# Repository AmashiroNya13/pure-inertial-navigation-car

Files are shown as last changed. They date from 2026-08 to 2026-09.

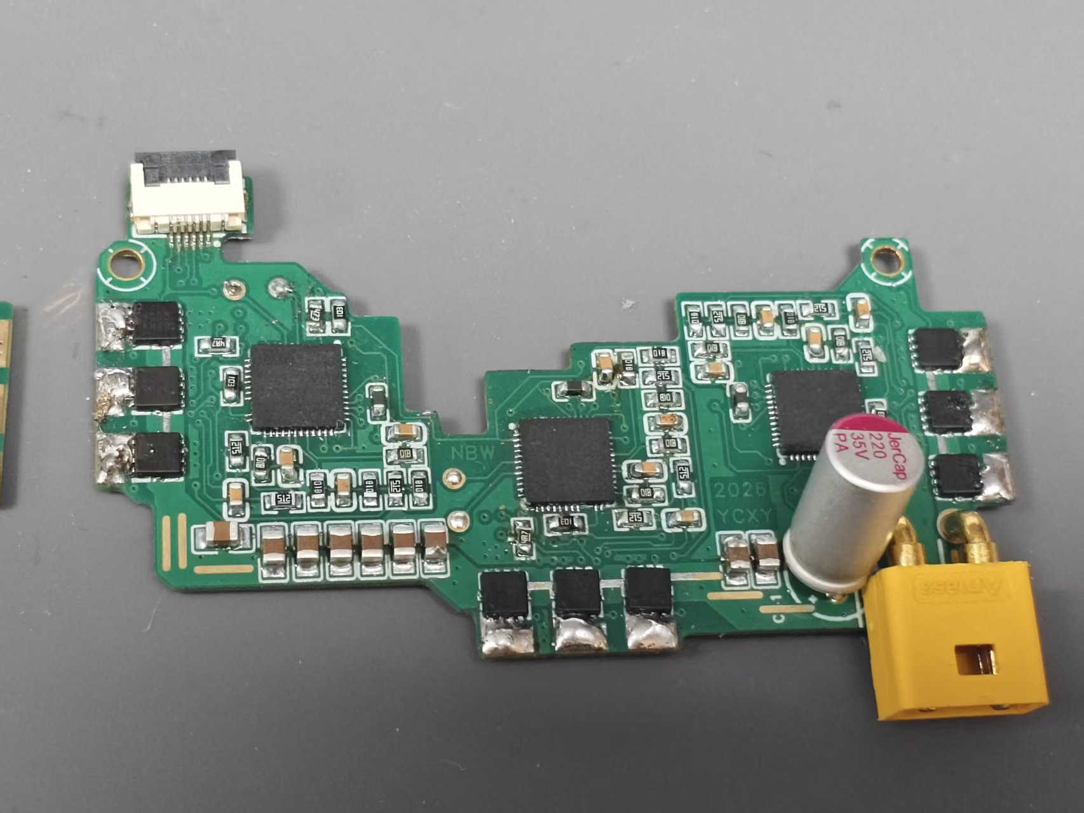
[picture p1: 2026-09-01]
images/4c2e1453128bda9ba8b21bae105e2d56.jpg

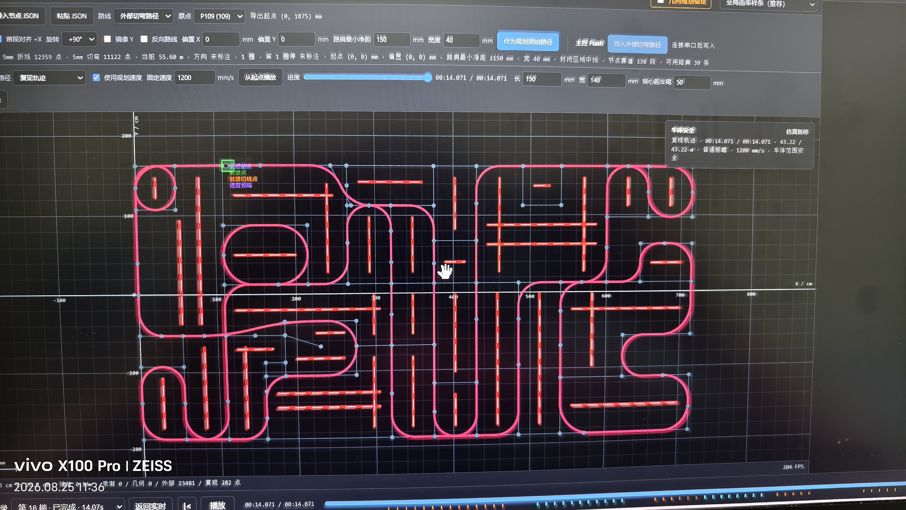
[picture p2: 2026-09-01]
images/IMG_20260825_113613.jpg

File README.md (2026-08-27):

# 21届纯惯导车开源项目

本仓库整理了纯惯导小车的控制软件、上位机工具、硬件资料和机械资料。项目用于路径采集、节点地图规划、路径上传、纯惯导复现与数据可视化。

> 安全提示：本项目涉及高速电机、无刷电调、负压和移动平台。首次使用必须架空车辆，使用保守的速度与加速度参数，并确认急停可用。

> **重要文档**：
> - [纯惯导软件设计说明](docs/INERTIAL_NAVIGATION_SOFTWARE.md)：IMU、编码器、双自由度角度环、速度前馈、路径与修正思路。
> - [纯惯导机械设计说明](docs/INERTIAL_NAVIGATION_MECHANICAL.md)：电机、负压、结构、减振、底盘和装配经验。
> - [纯惯导硬件设计说明](docs/INERTIAL_NAVIGATION_HARDWARE.md)：电调、双 IMU、屏蔽、编码器连接和后续硬件方向。
> - [机械采购与加工清单（Excel）](docs/MECHANICAL_PROCUREMENT_LIST.xlsx)：采购链接、CNC/3D 打印需求、在售核验与下单规格。

## 目录

```text
.
├── software/
│   ├── firmware/
│   │   ├── main-controller/ # TC2xx 主控：惯导、路径、速度和姿态控制
│   │   ├── drive-esc-ai8051u/   # 行进电机 AI8051U 电调
│   │   └── suction-esc-ai8051u/ # 负压电机 AI8051U 电调
│   └── tools/
│       ├── PathCapture/     # 串口上位机、路径上传与复现数据可视化
│       └── path-tools/      # 节点坐标规划器、路径日志查看器
├── hardware/
│   ├── schematics/        # 主控原理图
│   └── README.md          # PCB、BOM 与接线资料的发布约定
├── mechanical/            # CAD、装配图与机械 BOM
├── docs/                  # 使用、接口与调参说明
└── archive/               # 本地导入归档，不应推送到公开仓库
```

## 快速开始

### PathCapture 上位机

需要 Python 3.8 或更高版本。Windows 下双击：

```text
software/tools/PathCapture/launch.bat
```

首次启动会创建本地 `venv` 并安装依赖，浏览器随后打开 `http://localhost:5000`。更多使用方法见 [software/tools/PathCapture/README.md](software/tools/PathCapture/README.md)。

### 节点坐标规划器

直接使用浏览器打开：

```text
software/tools/path-tools/tools/node_coordinate_viewer.html
```

它可导入节点坐标、手动连接路线、做切弯与速度规划，并导出供 PathCapture 使用的 JSON。

## 发布前待补资料

- 在 `hardware/` 放入原理图、PCB、BOM、供电与接线说明。
- 在 `mechanical/` 放入 CAD 源文件、导出 PDF、装配说明和紧固件清单。
- 填写实车参数与安全范围，尤其是轮距、轮周长、减速比、PWM 上限和负压配置。

## 授权状态

当前尚未指定仓库整体许可证。公开前请逐项核对芯片 SDK、IDE 模板、逐飞库及其他第三方内容的原始许可证与再分发条件，再为你拥有版权的内容添加 `LICENSE`。

已识别到的第三方组件和发布边界见 [docs/THIRD_PARTY_NOTICES.md](docs/THIRD_PARTY_NOTICES.md)。

## 致谢与上游

主控工程的早期基础参考了 [XCELINE / MotorCycle](https://gitee.com/xceline566/motorcycle) 的第二十一届智能车单车定向开源项目。感谢 XCELINE 公开基础工程与文档。

本仓库不是该项目的官方分支：路径复现、车辆控制、速度与姿态策略、串口协议、路径工具及上位机均已进行了大量改动和扩展。上游来源、版本与许可证边界见 [docs/UPSTREAM.md](docs/UPSTREAM.md)。

`archive/` 存放本次整理前的原始导入压缩包，仅供本地追溯，已由 `.gitignore` 排除。

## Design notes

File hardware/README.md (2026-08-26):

# 硬件资料

`schematics/` 当前包含主控原理图 PDF。请在此目录继续放入与公开版本一致的：

- 原理图 PDF 与源文件
- PCB 生产文件和版本号
- BOM 与可替换料说明
- 接线图、供电范围、接口定义
- 传感器、电机、电调和负压模块的型号与安装方向

建议将每个 PCB 版本的生产文件、BOM、装配图放在同名版本子目录中。不要提交包含账户、订单、收货信息或厂商私有工程数据的文件。

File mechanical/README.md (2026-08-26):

# 机械资料

请在此目录放入与公开版本一致的：

- CAD 源文件与通用交换格式（STEP/DXF/PDF）
- 整车装配图
- 零件清单与紧固件规格
- 关键尺寸、材料、加工和安装注意事项

建议在每次改版时在文件名或附带的变更记录中标明版本。

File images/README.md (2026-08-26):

# 文档图片

本目录用于 README、使用说明和发布页中的展示图片，不存放原理图、PCB 生产文件或 CAD 源文件。

建议按以下名称放置图片：

| 文件名 | 内容 |
| --- | --- |
| `vehicle-overview.jpg` | 完整车辆正面或俯视图 |
| `vehicle-undercarriage.jpg` | 底盘、轮组与负压结构 |
| `electronics-overview.jpg` | 主控、行进电调、负压电调与接线概览 |
| `pathcapture-overview.png` | PathCapture 上位机界面 |
| `node-planner-overview.png` | 节点路径规划器界面 |
| `track-run.jpg` | 赛道运行或路径复现画面 |

图片应避免展示个人信息、串口号、账号、订单或无关的电脑桌面内容。优先使用清晰的 PNG/JPEG，并保持单张图片在合理体积内。

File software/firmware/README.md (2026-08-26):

# 固件工程

## 子项目

| 目录 | 目标 | 工具链 |
| --- | --- | --- |
| `main-controller/` | 车辆主控、惯导路径、速度与姿态控制、串口协议 | Infineon AURIX Development Studio + TASKING |
| `drive-esc-ai8051u/` | 行进电机的 AI8051U 无刷电调 | Keil C251 |
| `suction-esc-ai8051u/` | 负压电机的 AI8051U 无刷电调 | Keil C251 |

三个固件工程需要分别编译、烧录。两块 AI8051U 板不能混刷：行进电调接收主控的行进 PWM，负压电调只驱动负压电机。每次烧录前都应核对目标板、接线、电源与对应目录。

## 第三方代码

`main-controller/Libraries/`、两套电调的逐飞组件、芯片头文件、SDK 及 IDE 工程模板可能带有独立许可证。公开发布前必须保留各文件原有版权声明，并按原许可证确认是否允许再分发和商用。

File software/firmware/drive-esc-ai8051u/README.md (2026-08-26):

# 行进电机 AI8051U 无刷电调固件

这是行进电机使用的 AI8051U 无感六步换相电调工程，使用 Keil C251 构建。它与同级 `../suction-esc-ai8051u/` 的负压电调是两套独立固件，不能混刷。

## 构建

1. 安装 Keil C251 与工程依赖的逐飞库。
2. 打开 `project/` 下的 `.uvproj` 工程文件。
3. 确认目标是行进电调板，并在不接动力电机或使用受限电源的条件下完成首次烧录与验证。

## 关键配置

主要控制参数在 `bldc/bldc_config.h`，包括 PWM 范围、最小/最大占空比、开环换相次数、闭环等待次数、速度增量限制和电机进角。

电调输入与主控 PWM 的协议、频率和量程必须一致。修改前先记录原始值；任何更改都应在架空状态验证低油门启动、停转、欠压保护和失控保护。

## 第三方声明

本目录含逐飞库与模板代码。必须保留原始文件头和版权信息，并在公开发布前确认原始许可证是否允许再分发。

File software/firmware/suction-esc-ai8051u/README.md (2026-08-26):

# 负压电机 AI8051U 无刷电调固件

这是负压电机使用的 AI8051U 无感六步换相电调工程，使用 Keil C251 构建。它与同级 `../drive-esc-ai8051u/` 的行进电调是两套独立固件，不能混刷。

## 构建

1. 安装 Keil C251 与工程依赖的逐飞库。
2. 打开 `project/` 下的 `.uvproj` 工程文件。
3. 确认目标是负压电调板，在不接负压电机或使用受限电源的条件下完成首次烧录与验证。

## 关键配置

主要控制参数在 `bldc/bldc_config.h`。负压电机的 PWM 量程、最大占空比、保护阈值与响应限制应按负压系统单独设置，不能复制行进电机参数。

## 第三方声明

本目录含逐飞库与模板代码。必须保留原始文件头和版权信息，并在公开发布前确认原始许可证是否允许再分发。

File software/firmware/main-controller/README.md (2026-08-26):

# 主控固件

这是基于 Infineon AURIX TC2xx 的 ADS/TASKING 工程，包含纯惯导路径记录与复现、速度环、航向控制、路径上传、光电与滑移观测相关模块。

## 打开与构建

1. 安装与工程匹配的 AURIX Development Studio、TASKING TriCore 工具链和芯片 SDK。
2. 在 ADS 中导入本目录为现有 Eclipse 工程。
3. 选择 `Mad_Circuits TriCore Debug (TASKING)` 构建配置。
4. 在未接电机的条件下先检查引脚、时钟、PWM、编码器、IMU 和串口配置。

工程链接脚本为 `Lcf_Tasking_Tricore_Tc.lsl`。构建产物应生成在本机目录，已由仓库根目录 `.gitignore` 排除。

主控原理图位于仓库根目录的 `hardware/schematics/`，不再混放在固件目录。

## 主要模块

| 路径 | 职责 |
| --- | --- |
| `src/app/module/module_vehicle_control/` | 速度、姿态、起步状态机与 PWM 输出 |
| `src/app/module/module_vehicle_path/` | 路径记录、规划、上传、复现与位置估计 |
| `src/app/module/module_vehicle_encoder/` | 轮速和编码器观测 |
| `src/app/module/module_vehicle_gyro/` | IMU 与姿态观测 |

## 参数与安全

实车参数和 PID 不应直接照搬。首次移植应从低速、低加速度、架空测试开始，逐项校验轮周长、轮距、减速比、编码器方向、电机方向、IMU 轴向和急停逻辑。

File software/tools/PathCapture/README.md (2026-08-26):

# PathCapture — High-Performance Real-Time Path Display

A high-performance, real-time 2D path visualization tool for robotics and embedded systems. Receives coordinate data via serial port and renders it on a Canvas-based web interface with smooth zooming, panning, and 20k+ point support.

## Features

- **Real-time rendering** — Canvas2D with `requestAnimationFrame` loop; handles 20,000+ points at 60 FPS
- **Serial data ingestion** — Reads `R(car_x,car_y),(lookahead_x,lookahead_y)` and `P(x,y)` messages via serial port
- **Three data layers** with independent visibility toggles and distinct colors:
  - 🟦 **Predefined Path** (persistent, blue)
  - 🟥 **Real-Time Track** (appends on arrival, red, with direction arrow)
  - 🟩 **Lookahead Point** (latest shown by default, toggleable history, green)
- **Zoom & Pan** — Mouse wheel zoom (centered on cursor), click-drag pan, pinch-to-zoom on touch devices
- **Auto-Fit** — Animated fit of visible data to the viewport
- **Light/Dark theme** — Default light theme with dark mode toggle; persists across sessions
- **Serial port picker** — Direct dropdown (no submenus); auto-refresh; baud rates up to 2,000,000
- **Replay sessions** — Each confirmed replay is stored as an independent run with a shared elapsed-time axis
- **Serial command console** — Send commands and inspect filtered RX/TX replies in the same window
- **Data persistence** — Save the baseline path and all replay runs as a version 3 JSON file
- **Status bar** — Live mouse world coordinates, zoom level, point counts, FPS
- **Keyboard shortcuts** — Arrow keys pan, `+`/`-` zoom, `F` or `0` auto-fit
- **Responsive** — Works on desktops and tablets; touch-friendly

## Quick Start

### Prerequisites

- Python 3.8 or later
- pip (Python package manager)

### Launch

**Linux / macOS:**

```bash
chmod +x launch.sh
./launch.sh
```

**Windows:**

```cmd
launch.bat
```

The script will:
1. Check for Python
2. Install dependencies (`flask`, `flask-socketio`, `pyserial`)
3. Start the web server on `http://localhost:5000`
4. Open your default browser automatically

### Manual Setup

```bash
cd PathCapture
pip install -r requirements.txt
python app.py
```

Then open **http://localhost:5000** in your browser.

## Usage

### Workspaces

The top segmented control separates tasks that use the same map:

- **实时监控** keeps serial recording, replay, emergency stop and run playback together.
- **规划验证** compares the untouched path, browser geometry result and firmware-equivalent speed plan. The path cursor shows the nearest/base point, steering lookahead, tangent sample and independent speed-preview point. A lateral-offset input makes cross-track behavior visible without altering the stored path.
- **外部路径** imports node-map JSON, previews the node polyline and exported cut-corner samples independently, then optionally promotes the selected route to the planning workspace.

The curvature and speed charts are linked by path distance. The speed chart exposes curvature, wheel-speed, forward-acceleration, backward-braking and final constraints instead of presenting only the final planned speed.

### Connecting to a Device

1. Connect your embedded device via USB serial
2. Select the **serial port** from the dropdown (click 🔄 to refresh)
3. Choose the **baud rate** (default: 115200; supports up to 2,000,000)
4. Click **Connect**

### Vehicle workflow

The mode badge follows vehicle replies; clicking a button does not change the mode optimistically.

| Action | Serial command | PathCapture behavior |
|---|---|---|
| Start recording | `vpath record` | Wait for `{pathinfo}record_start`, then clear the old blue baseline and display incoming path points |
| Stop and save recording | `vpath record stop` | Keep the completed blue path as the baseline |
| Start replay | `vpath replay` | Start a new replay run after the vehicle confirms replay start |
| Emergency stop | `vstop` | Send immediately; the current replay run is closed when stop/safety feedback arrives |

After replay finishes or stops, select a run at the bottom and use the time slider, play/pause button and speed selector. Imported files keep their recorded path as the blue baseline until the vehicle confirms a new recording.

### Geometry validation

Enter **规划验证** to configure browser-only geometry and speed planning:

- Blue points are the untouched recorded path.
- Orange points are the reconstructed geometric path.
- Every coordinate layer has an independent visibility switch. Recorded, geometry, firmware, external, replay and lookahead points can be compared and inspected in any workspace.
- **全局曲率样条（推荐）** fits one cubic parametric spline across the complete path. Detected straight sections receive strong TLS line constraints, while second- and third-control-difference penalties suppress curvature and curvature-rate discontinuities through compound and S bends.
- **分段回旋圆弧（旧）** keeps the earlier independent `line -> clothoid -> arc -> clothoid -> line` corner reconstruction for comparison.
- The curvature chart plots signed curvature against path distance. Hover an orange point to inspect its geometry type, curvature and radius.
- Enable **限制最小半径** and enter a radius in millimeters to search progressively smoother global splines. A result is marked **已满足** only after every planned point passes `abs(kappa) <= 1 / radius` and the complete curve remains inside the 120 mm offset guard. Dashed red lines show the selected curvature bound.
- Enable **横向偏移优化（实验）** to add coarse lateral-offset control points along the global spline. The browser performs projected coordinate searches inside the 120 mm corridor, directly penalizing curvature-limit violations, excessive displacement and abrupt offset changes. This can move individual bends instead of only increasing one global smoothing factor.
- The experimental optimizer is browser-only and intentionally disabled by default. It preserves path order but does not yet model measured left/right track boundaries, vehicle footprint or prove that the optimized path is globally optimal.
- **未满足** means the current search family did not find a valid curve inside the offset guard; it is not a mathematical proof that no possible path exists.
- A planned curve that still exceeds the 120 mm source-path offset guard after relaxation is rejected and displayed as the resampled source path.

The validator never overwrites the recorded path, sends planned points to the vehicle or changes replay control. The recommended method is a constrained parametric spline with curvature-related regularization; it is not yet a nonlinear direct optimization of `kappa(s)`.

### External node maps

Node-map JSON exported by `tools/node_coordinate_viewer.html` is accepted directly. Supported fields include `nodes[]`, `start_node_id`, `computed_shortest_route.full_path_node_ids` and `computed_shortest_route.speed_segments[].points_mm`.

The node viewer provides **下载 JSON** for a normal file workflow. Its **复制导出文本** output can also be pasted directly through PathCapture's **粘贴 JSON** dialog.

- The exported `start_node_id` is selected by default and remains at its exported `(x_mm, y_mm)` position.
- Editable start X/Y fields default to the exported start coordinates and translate the complete route to that absolute position.
- Selecting another origin restarts a closed route at that node and resets start X/Y to that node's exported coordinates.
- A shoulder layer is enabled by default on both sides of the selected external route. Its inner edge is 150 mm from the path and its width is 40 mm; both values remain editable.
- **首段对齐 +X** rotates the first route segment onto the inertial positive X axis.
- Additional `0°`, `+90°`, `-90°`, `180°`, Y mirroring and route reversal controls are applied around that origin.
- **节点折线路径** is the recommended raw input for browser geometry planning.
- **外部切弯路径** is a comparison layer by default, avoiding accidental double optimization.
- Exported coordinates do not carry the source tool's display-only `Y 向下` setting, so orientation is always explicit in the import controls.
- Imported X/Y controls are relative offsets and therefore start at `0, 0`; the exported origin coordinates remain the transform base. Shoulders are generated only from external node-track links, never from cut-corner samples. Each bounded region receives one thick line along its longer axis. The line starts from average Y or X, then follows the local maximum-clearance center as nearby node-road segments move inward. Every interpolated centerline section must retain the configured clearance plus half the shoulder width; impossible sections are omitted instead of crossing the road.
- The vehicle collision switch wraps the replay arrow with the configured body footprint. The replay coordinate and `theta_deg` define the motion-center pose; with the default 150 mm length and 50 mm rear-to-center mounting distance, the body extends 100 mm forward and 50 mm rearward from that point. Each safe-to-collision transition records replay time, traveled distance and coordinates.

The firmware speed planner uses the current defaults: 400-3200 mm/s, 25,000 mm/s² lateral and longitudinal limits, a 120 mm wheelbase, 200 mm at 500 mm/s after launch, and 300 mm terminal deceleration. These values can be adjusted in the planning workspace for comparison; browser planning does not write Flash or send commands to the vehicle.

### Data Format

The tool is adapted for the current Mad_Circuits serial replies. Each message must end with `\n` or `\r\n`.

| Format | Description | Layer |
|---|---|---|
| `{pathdump}index,x_mm,y_mm,theta_rad,speed_mm_s` | Dumped recorded/planned path point | Blue path |
| `{path}x_mm,y_mm,theta_deg,index,record_dist_mm,...` | Path point printed while recording | Blue path |
| `{vrpl1}pose_x_mm,pose_y_mm,pose_theta_deg,base_x_mm,base_y_mm,base_theta_deg,cte_mm,along_mm,target_x_mm,target_y_mm` | Replay pose + current tracking target | Red track + green target |
| `{vrpl2}...` | Target/actual wheel speed and compact angle diagnostics | Point details |
| `{vrpl3}...` | Target/final wheel PWM and ESC fault state | Point details |
| `{vrpl0}...`, `{vrpl4}...`, `{vrplg}...` | Point index, lookahead and replay startup phase | Point details |
| Binary replay frame `A5 5A` | Default compact equivalent of `{vrpl0}` through `{vrpl3}`; decoded by the backend | Red track + point details |
| `{vmark}add,kind,index,x_mm,y_mm,theta_deg` | Manual turn-in/turn-out marker | Green target layer |

Legacy `P(x,y)` and `R(car_x,car_y),(lookahead_x,lookahead_y)` lines are still accepted for compatibility.

Replay telemetry defaults to the compact binary frame. Use `vtelemetry text` for legacy text diagnostics,
`vtelemetry binary` to restore the compact mode, and `vtelemetry status` to query the current mode.
Speed-loop ground tests keep the original `{vspd}` text packet unchanged.

**Examples:**

```
{pathdump}0,100.000,200.000,1.570796,500.000
{path}110.000,210.000,90.000,1,12.000,0,0,0,0,0,0,0,0,0,0
{vrpl1}120.0,220.0,91.00,111.0,211.0,90.0,9.0,10.0,150.0,250.0
{vmark}add,in,3,130.000,230.000,92.000
```

- `{pathdump}begin,...` clears the blue path before a new dump, preventing repeated dumps from stacking.
- Firmware coordinates are millimeters; map axes and mouse coordinates are labeled in centimeters.
- Hover a point to inspect position, tracking target, cross-track error, planned/actual speed, wheel speed and PWM.
- Enable **Diagnostics** only when tuning the controller. It adds angle/yaw, tangent, base-point and ESC details.
- Deep diagnostics (`vrpl5/6/7`), IMU raw data, phototube data, Flash logs, startup messages, malformed lines and unknown prefixes are intentionally filtered out.
- Saved files contain structured visualization data only. Raw serial lines are no longer duplicated into the JSON file; version 1 files remain loadable.

### View Controls

| Action | Control |
|---|---|
| Zoom | Mouse wheel / `+` `-` keys / toolbar buttons |
| Pan | Click & drag / Arrow keys |
| Auto-fit | **Auto Fit** button / `F` key |
| Pinch-zoom | Two-finger gesture (touch devices) |

### Visibility Toggles

Use the checkboxes in the toolbar to show/hide:

- **Path** — Predefined trajectory points (blue)
- **Real-time** — Live car track (red)
- **Lookahead** — Preview point (green)
- **History** — When checked, all past lookahead points are displayed instead of only the latest

### Saving & Loading Data

- **Save** — Downloads a version 3 JSON file containing the baseline and every replay run
- **Load** — Click **Load**, select a `.json` file (previously saved or server-generated)

The JSON format:

```json
{
  "version": "3.0",
  "saved_at": "2026-07-14T14:00:00",
  "predefined": [{"x": 1.5, "y": -2.3, "t": 0.001}, ...],
  "realtime":  [{"x": 0.0, "y": 0.0, "t": 0.002}, ...],
  "lookahead": [{"x": 1.5, "y": -2.3, "t": 0.002}, ...],
  "replay_runs": [{
    "id": 1,
    "status": "completed",
    "points": [{"x": 0.0, "y": 0.0, "elapsed_s": 0.0}, ...],
    "lookahead": [{"x": 1.5, "y": -2.3, "elapsed_s": 0.0}, ...]
  }]
}
```

Version 2 flat files are accepted and are converted to one imported replay run in memory.

## Architecture

```
PathCapture/
├── app.py                  # Flask + Socket.IO backend; serial reader thread
├── static/
│   ├── index.html          # Single-page application shell
│   ├── style.css           # Light/dark theme, responsive layout
│   ├── app.js              # Canvas2D renderer, socket.io client, interaction
│   ├── geometry-planner.js # Browser geometry algorithms
│   ├── firmware-speed-planner.js # Firmware-equivalent speed constraints
│   └── external-path.js    # Node-map parsing and coordinate transforms
├── launch.sh               # Linux/macOS launcher
├── launch.bat              # Windows launcher
├── requirements.txt        # Python dependencies
└── README.md               # This file
```

### Data Flow

```
Embedded Device ──(serial)──> Serial Reader Thread ──> process_line()
                                    │
                              socketio.emit('serial_data')
                                    │
                              WebSocket ──> Browser ──> Canvas2D Renderer
```

## Performance Notes

- Uses **Canvas2D** with view-transform rendering — point coordinates never change, only the transform matrix
- Grid lines are clipped to prevent excessive draw calls at extreme zoom levels
- Dirty-flag optimization avoids re-rendering when nothing changes
- Device pixel ratio clamped to 2x for sharp rendering without excessive GPU load
- Tested rendering 20,000+ polyline points at 60 FPS on modern hardware

## Troubleshooting

| Issue | Solution |
|---|---|
| "No ports found" | Ensure device is connected and drivers are installed; click 🔄 to refresh |
| "Access denied" (Linux) | Add user to `dialout` group: `sudo usermod -a -G dialout $USER` (log out/in after) |
| Port in use | Close other terminal/serial monitor programs (Arduino IDE, PuTTY, screen, etc.) |
| Page shows "Unable to connect" | Ensure `python app.py` is running; check port 5000 isn't in use |

## License

MIT

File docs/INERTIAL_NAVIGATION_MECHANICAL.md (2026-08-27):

# 纯惯导机械

> 本文记录本车的机械设计思路、实际选型与后续设想。性能数据来自作者当时的实车记录，受轮胎、负压、赛道、电池和装配状态影响很大，不应直接作为复现或安全边界；首次调试请从保守速度和加速度开始。

## 设计目标

机械设计的目标是在保持低重量和高性能的同时，保留可拆装、可调整的结构，并尽量控制成本。装配复杂度可以接受，但必须换来可靠的车载平台和明确的维护空间。

## 行进与负压

- **行进电机**：T-Motor 1404、3800 KV 外转子无刷电机。作者记录的 3S 工况下持续转速约为 32000 RPM、电流约为 10 A；选择重点是尺寸不遮挡轮毂安装、转速合适、扭矩和电压匹配，以及可实现的减速比。
- **负压电机**：致盈动力 1202.5、6000 KV 无刷电机，配合龙邱方案扇叶。作者曾记录到约 1600 g 负压，实际可用上限仍需实测确认。
- **车辆记录**：原车采用六步换向驱动，纯惯导版本重量约 99 g；作者曾观察到约 1000 g 负压、约 9 A 电流的工况。轮胎摩擦系数和负压效率是性能上限的主要约束，不能仅由电机转速推断过弯能力。

## 结构与材料

- 主结构使用碳纤维底板和加强筋，配合 TA2 钛合金螺丝、超小碳钢螺丝、铝柱。
- 带齿轮的一体化轮毂采用嘉立创 3D 打印 PA12S。
- 轮轴使用两颗 PEEK 轴承、垫片、PEEK 螺丝和铝柱。四个车轮共八颗轴承，载荷有较大余量；相对于碳钢轴承，该方案有利于减重。
- 编码器固定采用 PEEK 螺丝、带螺纹铝边板和铝柱组成的刚性平台。磁铁间距约 1 mm，通过 FPC 连接主板，作者实测数据稳定。

## 减振与 IMU 安装

主 PCB 与 IMU 小板分离安装。TC264 主板上放置聚氨酯海绵，IMU 小板上的洋白铜屏蔽罩通过 FPC 与主板传递数据。作者实测，该方案可隔绝大部分 6000 KV 无刷电机在约 83% 油门以内的振动。

减振件必须在载荷下产生弹性形变，才能通过能量耗散发挥作用。后续可把主板从加强筋结构中独立出来，改用飞控常见的球形减振柱；是否更优仍应以 IMU 数据验证。

## 光电管与底盘

光电管需要相对平稳的检测面。由于前置结构可能使悬空底板振动，车头采用较轻的铝合金盘头螺丝作为滑动支撑，略高于底盘，以获得少量负压并改善数据清晰度。

底盘并非越低越好：负压会向下压车，而此类车辆轮距较大，底盘触地会使负压失效。底盘离地高度应结合负压膜投影面积、赛道平整度和触地风险一起设计。当前车辆重心整体均衡、略偏后，离地高度在约 1 cm 以内。

## 装配与可调性

- **CNC 加工要求**：所有需要螺丝固定的 CNC 件，下单时必须按图增加并加工 **M2 螺纹孔**；不得只保留普通定位孔或光孔。加工完成后应使用 M2 螺丝逐孔试装，确认螺纹完整、孔位与装配体一致。
- 铝柱相对于常见尼龙柱可把外径压缩到约 3.5 mm，有利于 PCB 开孔、留白和螺丝固定；缩小体积后重量也接近或优于尼龙柱。
- PEEK 螺丝比尼龙螺丝刚度高，适合需要可靠夹紧的小型结构，同时保持轻量。
- 电池接口可在比赛常用的 300 mAh 与 180 mAh 小电池之间转换。为便于安全插拔，建议使用独立转接线。
- 加强筋上的两道槽用于扎带限位电池的左右及部分上下运动；需要更强限位时，可在电调上方增加 3M 胶辅助固定。
- 边板的椭圆槽用于调整轮毂齿轮啮合松紧，并为更换减速比保留位置。

## 后续方向

若负压、轮胎和结构进一步优化，车辆上限仍有提升空间。作者曾设想更高负压、更小减速比、4600 KV 电机或 4S 电池等方案；这些改动会显著提高机械、电调、热管理和安全要求，必须重新完成静态、架空和低速实车验证。

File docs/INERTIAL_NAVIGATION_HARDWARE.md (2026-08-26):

# 纯惯导硬件

> 本文记录本车硬件架构的设计经验。它不是可直接照抄的原理图或 BOM；供电、接地、烧录、散热和保护设计应以仓库当前硬件资料及实物验证为准。

## 电调架构

行进端采用逐飞 AI8051 电调方案，并改为一拖三结构；软件侧已做针对本车的调整。电调使用与构建说明见仓库中独立发布的行进与负压电调工程。

AI8051 的烧录接口必须预留。三块 8051 的反复烧录会直接影响维护效率；主控烧录口的串口可复用为高速无线串口，但使用前需确认电平、供电和串口复用状态。

## 双 IMU、减振与屏蔽

车辆采用双 IMU，通过洋白铜多点接地屏蔽电磁干扰，并帮助均匀分摊热量。

双 IMU 的价值主要在振动和零漂工况：当减振结构已能抑制主要振动时，两颗 IMU 的角度误差有机会呈相反趋势，平均后可让主体角度变化更缓慢。它不是无条件增益，必须以两路原始数据和融合结果验证。

洋白铜在本项目中承担多项作用：电磁屏蔽、散热均热、保护 IMU、粘接减振材料和增加适量配重。稳定的安装工况本身是惯导工程的重要部分。

## 编码器连接与磁屏蔽

编码器通过 FPC 连接到主板，体积小且实测数据稳定。项目曾设计 3D 打印屏蔽罩，但当前安装条件下未继续使用。

需要区分两类屏蔽：

- 良好接地的铝合金或铜对高频电磁场和电场屏蔽有帮助。
- 对强磁电机可能带来的低频磁场干扰，通常需要高磁导率材料，例如坡莫合金；普通接地铝或铜对此效果有限。

可行的机械方案是使用 3D 打印支架，使磁铁位于支架中，再将坡莫合金贴合在支架上形成磁屏蔽结构。是否需要实施应由编码器实际误码、角度稳定性和电机距离测试决定。

## 后续方向

后续硬件目标是继续提升供电、传感器和电调的稳定性，并评估 FOC 驱动方案。FOC 不只是替换算法，还涉及电流采样、PWM/ADC 同步、保护、位置反馈与整套驱动板设计，应作为独立硬件迭代完成验证。

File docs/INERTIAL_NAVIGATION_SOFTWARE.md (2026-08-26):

# 纯惯导软件

> 本文是本项目纯惯导软件的设计说明与工程经验记录。文中的频率、距离、阈值和参数用于说明当时的设计思路；实际默认值及可用范围应以当前源码和实车验证为准。

## 传感器

- **IMU**：负责航向偏移稳定。若航向歪斜，通常表现为路径整体旋转一个角度。
- **编码器**：负责横向误差锁定真实路径。若发生打滑，通常表现为平行路径但存在固定偏移。

偏移不止这两个因素，本文先聚焦于它们。

## 软件

### 1. IMU

IMU 获取角度通常有两种处理方式。

#### 1.1 角速度积分

主要由陀螺仪提供角速度，再根据某个时间戳完成积分。

1. **由主控提供时间戳**：会受到主控时间戳波动影响，而主控时间戳又受主控时序影响。因此应尽可能提高 IMU 数据处理优先级。这个思想同样适用于多数需要积分的场景，必须严肃考虑时序波动。
2. **由 IMU 提供时间戳**：理论上可能更准，但问题很多。最严重的是，这个时间戳并非 IMU 更新某条数据的时间戳，而是 IMU 自身当前时间戳，没有对数据点做标记；因此效果和主控时间戳相近，甚至可能更差。
3. **由 DMA 读取时获得时间戳**：这个时间戳较准确，实测可视为主控时间戳的上位推荐，能明显缓解时序不准问题，但实现仍有难度。

#### 1.2 IMU 自身四元数解算

由 IMU 自身完成独立四元数积分，输出 Game Rotation Vector 角，也就是向量角。该方式不必担心主控时序，也不会因 IMU 实时性要求侵蚀主控时序。

它仍有局限：难以进一步使用陷波等滤波算法，陀螺仪自身的静止修正算法精度有限，更新频率也较有限。滤波、静止修正和更新频率导致的问题在此不展开。

#### 1.3 本项目 IMU 与初始化现象

本项目使用 ST 的 LSM6 系列、带自解算四元数的版本。其自解算最高输出 480 Hz 角度数据，原始角速度和加速度最高输出 7000 Hz；此外还能读取温度、零偏修正数据和时间戳。

实测中，该 IMU 开启自解算 Game Rotation Vector 输出后的前 17 秒，数据会呈现“耐克状”弯钩，并可能形成永久性误差。因此上电后应禁止这 17 秒内的角度累计更新；期间并不要求车辆静止。

#### 1.4 零偏与外部干扰

IMU 数据通常包含零偏并会受到外部干扰。这里的外部干扰主要指负压振动和行进振动。

零偏通常由温漂、随机游走、电磁噪声和固定零偏构成：

- **温漂**可以通过恒温电路控制，但面对双 IMU、多 IMU、重量限制和布板限制，实现并不容易。一个思路是由主控通过 PWM 控制电阻的电流、电压以实现恒温；多 IMU 情况下 PWM 需求和复杂度都会增加。
- **随机游走**正负平均后通常不需要额外修正。
- **电磁噪声**个人观察中影响较大。这里主要隔离高频噪声，可使用马口铁、洋白铜、不锈钢，甚至铝合金进行多点接地隔离。项目中选择了约 0.15 mm 厚的洋白铜：不锈钢与马口铁款式较少，铝合金虽然更轻但难焊接、制作成本高，且担心焊接失败影响隔离效果。

固定零漂的处理思路是：关闭角度输出的自修正寄存器，把 IMU 静置在稳定桌面上，通过至少 409600 波特率的高速串口打印角度数据，确保环境没有异常振动，放置一整夜，再分析斜率以标定粗略零偏。

开机 17 秒后，使用加速度计、陀螺仪和编码器共同检测静止。静止时的加速度、角速度和编码器跳动数据可用于分析合理阈值。在连续共同静止的死区内，IMU 禁止角度更新，并在固定零偏粗略处理后做更细致的零偏处理。

为避免时间跨度过大导致修正不够实时，设计上每 5 秒解算并使用一次零偏。退出静止的阈值略小于进入阈值；采用计数退出机制，即运动状态 `+1`、非运动状态 `-0.5`。另外通过小数据窗口缓存，保证进入/退出判断过程中用于确认的帧也能按正确状态重新处理。目标是在上电 17 秒后，只要放下不动就进入静止状态，保持极低漂移并可实时修正；灵敏度达到点击鼠标或手放在桌上抖腿会被识别为运动，同时尽量避免误判。

外部干扰中，行进端因硅胶胎减振且相对稳定，影响可在一定程度上忽略。负压端固定在底板，高速旋转并与空气做功，抖动更大、频率更高、难抓取也难滤除。由于车况变化较大，基于模型的减振或陷波较难稳定标定，更适合从机械侧使用海绵减振、分板减振或减振柱等方案。

以上是作者对 IMU 软件的部分理解，请结合实际情况自行判断。

### 2. 编码器

本项目使用 SPI 通信的 14 位编码器，以 1920 Hz 通过 DMA 自主读取角度数据并计算差值，属于 M 法测速。相对 T 法，其高速性能更好；同时因时序准确，实际效果较好。

编码器算法本身没有特别复杂的计算。作者不建议为了抑制齿槽或齿轮效应带来的抖动而盲目增加低通滤波：这类抖动很难被有效滤除，低通滤波反而引入相位滞后。去掉不必要滤波后，响应可能更快、修正更及时、实际波动也可能更小。该结论应以具体硬件数据验证。

## 控制算法

电调侧采用六步换向和过零校正。主控侧输出 PWM，使用双串 PID：480 Hz 的双自由度角度环，连接 1920 Hz 的前馈速度环。

### 1. 双自由度角度环

惯导路径控制通过转向前瞻目标的 `x/y` 坐标与自身 `x/y` 坐标计算目标角度差，再送入角度环。角度环为作者实现的“双自由度 PD”：经典 PD 加微分先行 D，再用二自由度约束对两个 D 做加权调节。

设计来源于两种观察：

- 使用经典 PD 时，过弯通过率高，但摆动较大，路径不够准确。
- 使用微分先行 PD 时，贴路径效果很好，但偶发转弯突然失控，且失控位置可能高度一致。

二者融合后，在 PD 固定且不需要精确重新调参的情况下，可以主要调整自由度：自由度较低时，过弯成功率更高，但会带来更平滑、略超调且不再紧贴路径的感觉；自由度较高时，路径跟随更紧，但会降低过弯成功率。实测中较高自由度可达到较好的综合效果。角度环不建议额外使用前馈。

### 2. 速度环与前馈

角度环计算出的相反速度误差分别送到左右轮速度环。速度环由前馈加 PI 构成，速度目标值需经过加速度限制以限制速度阶跃斜率。这是速度规划的前置条件，可从源头降低打滑、起步翘头和停车翘尾风险。

加减速限制是最大限制。具体加减速能力应来自实车标定：在无角度环的闭环速度环直线测试中，于多个速度点测得稳定 PWM，形成前馈表；目标区间之间进行线性插值，即可得到相对准确的全速度段前馈。作者记录中，单 PI 响应约 40 ms、单前馈约 30 ms，二者结合可降至约 17 ms 或更低。最后通过 PWM tick 斜率控制输出左右轮 PWM，主控只需限制明显错误输出，电调侧保留更严格的限制。

### 3. 前瞻解耦

速度前瞻和角度前瞻分别影响基础目标速度和转向角度。因此，“角度环串速度环”在本项目架构中并非传统串级：传统串级中上一级输出全额管控下一级；这里角度环输出的是差速，速度环将差速叠加到基础目标速度形成最终目标速度。

将两类前瞻分开可解耦基础目标速度和角度控制。若解耦不到位，速度规划可能成为一厢情愿：作者曾在固定 3.5 m/s 与最高直道规划 3.5 m/s 的测试中发现，虽然后者会因摩擦力规划而在弯道降至约 2.5 m/s，直道仍可能比原本更快，而弯道反而无法通过。

后续将速度前瞻设为约 1 cm、转向前瞻约 21 cm 后，弯道通过率明显提高。速度前瞻调至 2 cm 时，在相同速度下出现约 5 cm 的严重横向打滑；调小后仍可能打滑但幅度较小。可见在较大加减速限制下，该阈值较严格。因此应优先确保速度与角度控制真正解耦，再讨论速度规划效果。

## 惯导路径与修正

### 1. 路径表示和导入

作者认为，仅计算和记录 `x/y` 坐标是较优的惯导路径表示；单纯曲率或路程记录缺少点间框架约束，难以纠正，只能反复复现。项目以约 5 mm 间隔记录一个 `x/y` 点到 Flash。

转向目标角由路径 `x/y` 坐标与实时自身位置计算，频率与转向环一致，为 480 Hz。高速时必须注意离散位置记录：转弯曲率变化应连续，否则会在某些帧引入运行毛刺和 `x/y` 错位。

因此路径使用 Web 工具导入并保存到 Flash，以便人为控制路径、平滑路径和降低曲率阶跃。若电调能接受更高的速度环频率，例如 2880 Hz，还可以固定基础速度并依据编码器单独改变路程，进一步提高操控能力；建议速度环频率选用基础频率的整数倍，优先为 2 的倍数。

### 2. IMU 与编码器交叉修正

惯导修正要求 IMU 和编码器分别维护一套角度。编码器角度依赖轮距计算，但实测中轮距随速度和转弯半径变化，难以细致标定，因此不建议过度追求单一精确轮距。

获得两套角度后，应持续比对最近窗口内的角度差变化。一旦评估差值过大，例如重合率低于约 84%，可把 IMU 角度视为编码器角度，并通过轮距反推编码器路程，以修正总里程。

Flash 读取必须使用缓冲区并进行无缝切换；否则不仅无法实时运行，也可能卡死并造成撞车风险。

### 3. 偏移来源与路径规划

惯导偏移可能来自：

1. 航向角漂移。
2. 坐标记录离散或遗漏。
3. 编码器打滑。
4. 路径本身的问题，即“以什么路径为复现基准”。

路径规划建议通过 Web 导入 5 mm 离散节点。该方法不仅支持提前切弯，也可以利用摩擦圆算法为每个点给出规划速度和切弯半径，对精准惯导控制有帮助；还可扩展禁修区等功能。

### 4. 当前前瞻设计与后续设想

作者记录的常态前瞻为：约 1 cm 速度前瞻、约 21 cm 转向前瞻，以及基于转向前瞻的约 3 cm 切线前瞻。车辆自身坐标超过上一个弯道的出弯点后会进入直线状态；此时前瞻直接盯住下一个弯道的入弯点，以获得更强的直道抗扰动效果。

后续可考虑为每个弯道建立标定：上位机将转弯处理为恒定转弯半径，摩擦圆算法得到相对稳定的弯道速度，每个导入点带规划速度。在恒定转弯半径、恒定过弯速度和恒定基础速度下跑一趟弯道，即可观察弯中横向偏差，并通过增减当前转向前瞻距离形成“速度-最佳前瞻距离”表。这样直道可按下一个弯道提前预瞄，弯道则按速度选择更合适的前瞻距离，使控制进一步精细化。

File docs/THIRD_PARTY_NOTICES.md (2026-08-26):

# 第三方组件与发布边界

本文件记录已识别的第三方内容。它不是许可证替代品；发布者须在推送公开远端前确认每个来源的具体再分发条件。

| 位置 | 来源/用途 | 当前处理 |
| --- | --- | --- |
| `software/firmware/main-controller/` 的早期工程基础 | [XCELINE / MotorCycle](https://gitee.com/xceline566/motorcycle)，GPL-3.0 | 本项目为大幅修改后的独立仓库，保留上游归因并遵守适用的 GPL-3.0 条款 |
| `software/firmware/main-controller/Libraries/` | Infineon AURIX TC26B iLLD、寄存器定义与平台组件 | 保留原始版权头；根据各文件原始许可证发布 |
| `software/firmware/main-controller/user/` 与工程模板 | Infineon/ADS 工程模板 | 保留原始版权头；不纳入未来自有代码许可证 |
| `software/firmware/drive-esc-ai8051u/` | 行进电机：逐飞科技 AI8051U 库与无刷电调工程 | 文件头说明含非商业限制，不能被仓库未来的 MIT/GPL 许可证覆盖 |
| `software/firmware/suction-esc-ai8051u/` | 负压电机：逐飞科技 AI8051U 库与无刷电调工程 | 文件头说明含非商业限制，不能被仓库未来的 MIT/GPL 许可证覆盖 |
| `software/tools/PathCapture/` | 本项目上位机与网页工具 | 作者需确认所有文件均为自有或兼容许可后再授权 |
| `software/tools/path-tools/` | 本项目节点规划与路径查看工具 | 作者需确认所有文件均为自有或兼容许可后再授权 |

## 发布建议

1. 自有代码与第三方目录分开授权，不要在根目录许可证中声称覆盖整个仓库。
2. 若逐飞代码没有明确的公开再分发授权，公开仓库应改为仅保留你的差异补丁、配置文件与获取说明。
3. 每次新增 SDK、算法库、字体、图片或数据文件时，都在本表补充来源和许可证。

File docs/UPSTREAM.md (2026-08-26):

# 上游来源

## MotorCycle

- 上游仓库：[XCELINE / MotorCycle](https://gitee.com/xceline566/motorcycle)
- 作者：XCELINE
- 本地核对的上游版本：`7d0cf85`
- 上游许可证：GNU GPL-3.0

本项目的 TC2xx 主控工程以该项目的早期工程结构和部分基础实现为起点，后续已对路径复现、车辆控制、速度和姿态策略、串口协议、路径工具与上位机进行了大量修改和扩展。

本仓库不是上游的官方 fork，也不应将后续新增内容归因给上游作者。与此同时，基于上游 GPL-3.0 代码的部分仍须遵守其适用的许可证义务；逐飞、Infineon 等其他第三方内容继续以各自原始许可证为准。

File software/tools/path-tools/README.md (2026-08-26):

# 路径规划工具

本目录提供无需构建的本地工具。

| 文件 | 用途 |
| --- | --- |
| `tools/node_coordinate_viewer.html` | 节点坐标导入、手动路线连接、切弯、速度规划与 JSON 导出 |
| `tools/amr_path_viewer.html` | 路径与惯导数据查看 |
| `tools/path_log_viewer.py` | 日志辅助查看工具 |

## 使用

直接用现代浏览器打开 `tools/node_coordinate_viewer.html`。规划完成后导出 JSON，再在 PathCapture 的“外部路径”页面导入。

## 测试

安装 Node.js 后，在本目录执行：

```powershell
node tools/test_node_coordinate_viewer.js
node tools/test_amr_path_viewer.js
node tools/test_node_radius_cdp.js
```

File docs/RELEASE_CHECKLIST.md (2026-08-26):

# 公开发布检查清单

- [ ] 删除或确认不包含本地绝对路径、串口号、个人信息和赛场数据。
- [ ] 不提交 `archive/`、`venv/`、缓存、日志、二进制和构建产物。
- [ ] 检查主控固件、电调、SDK 和逐飞代码的原始许可证与再分发条件。
- [ ] 确认硬件和机械文件的版本、单位、层叠和生产注意事项。
- [ ] 架空实车验证急停、最低速度、串口连接、路径上传与停止命令。
- [ ] 在一台未配置开发环境的电脑上按 README 从零启动 PathCapture。
- [ ] 选择仓库地址后初始化 Git，并在首次提交前执行 `git status --ignored`。

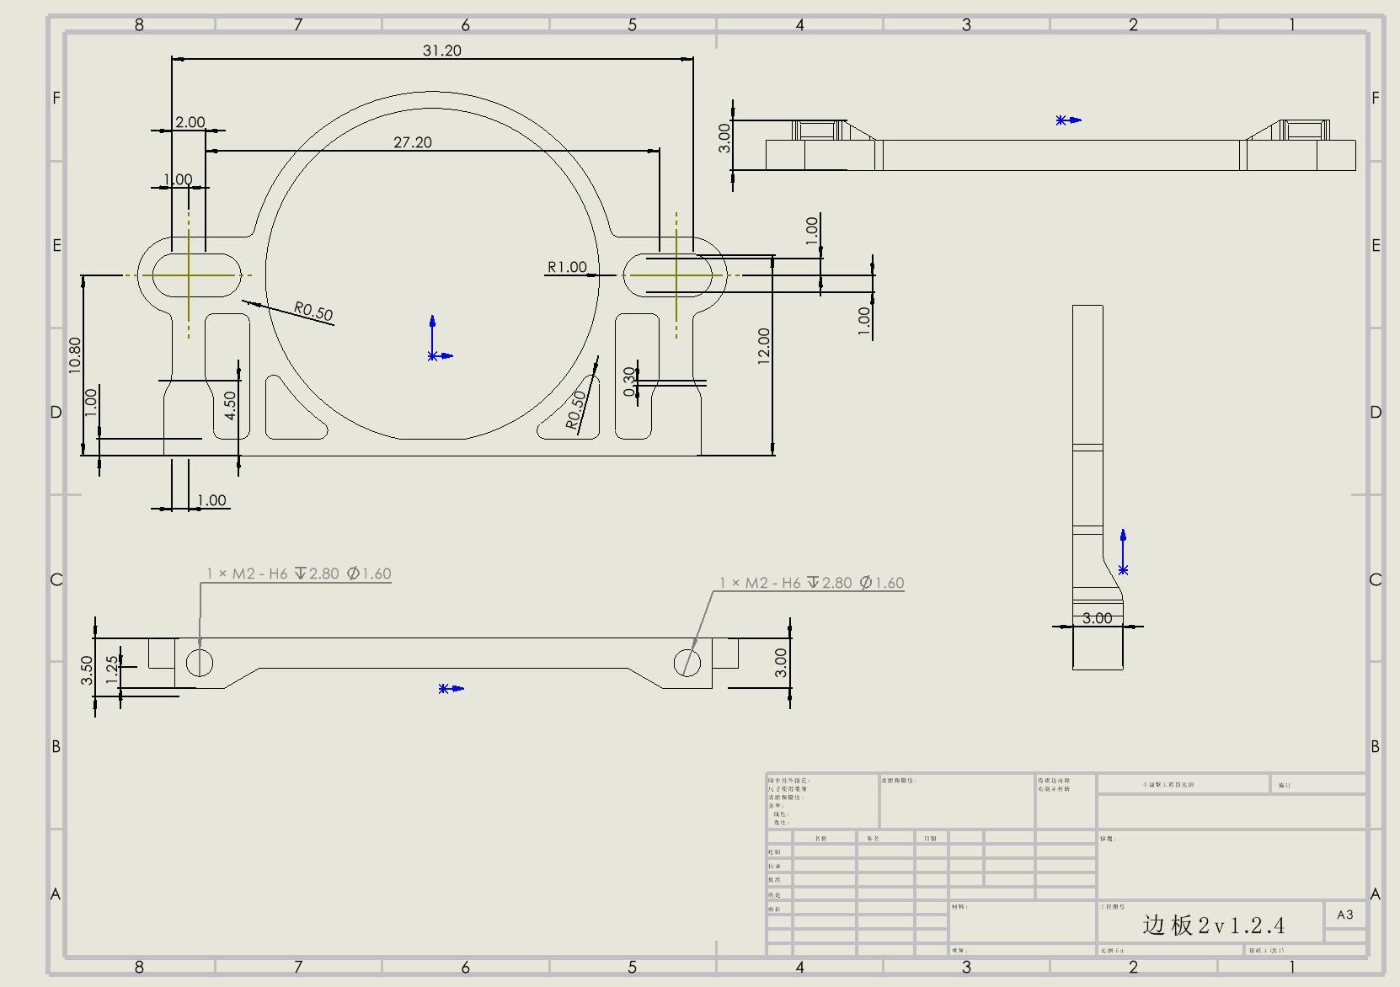
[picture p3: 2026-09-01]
mechanical/mechanical drawing/边板2v2.3.5.png

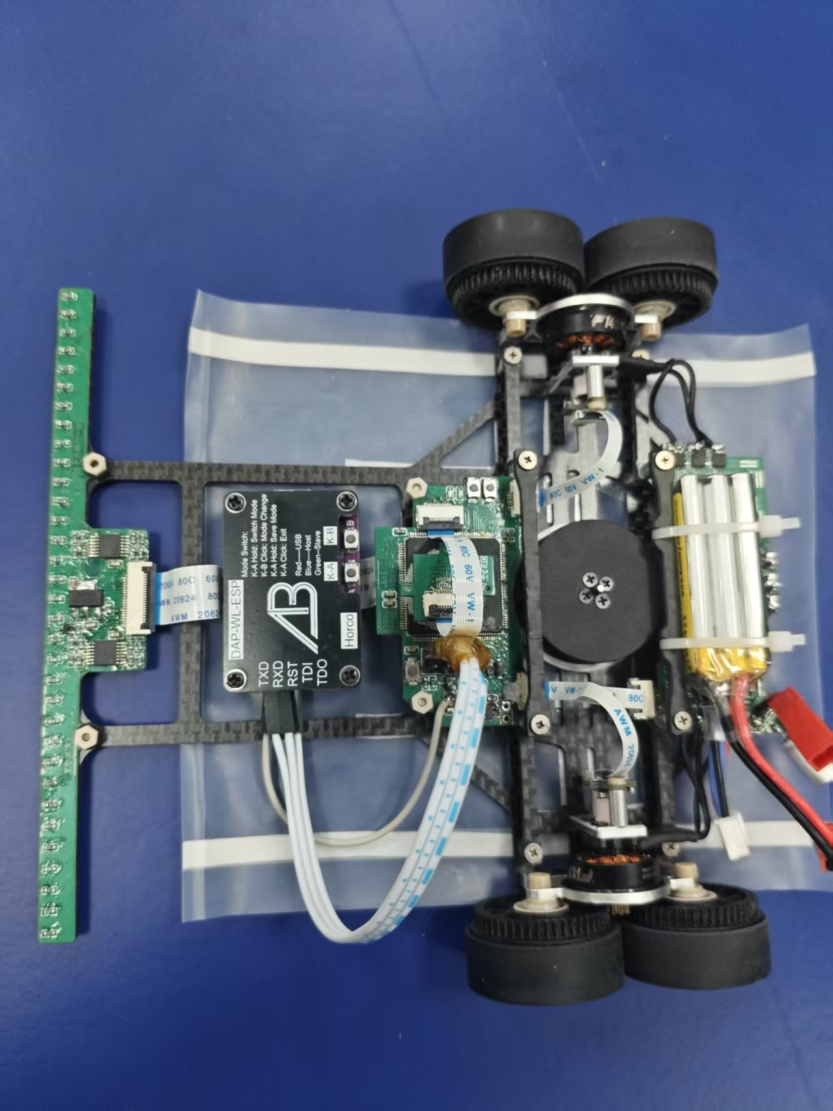
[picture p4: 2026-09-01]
images/f3f8274bfc2c42afd2de04dce35dd12d.jpg

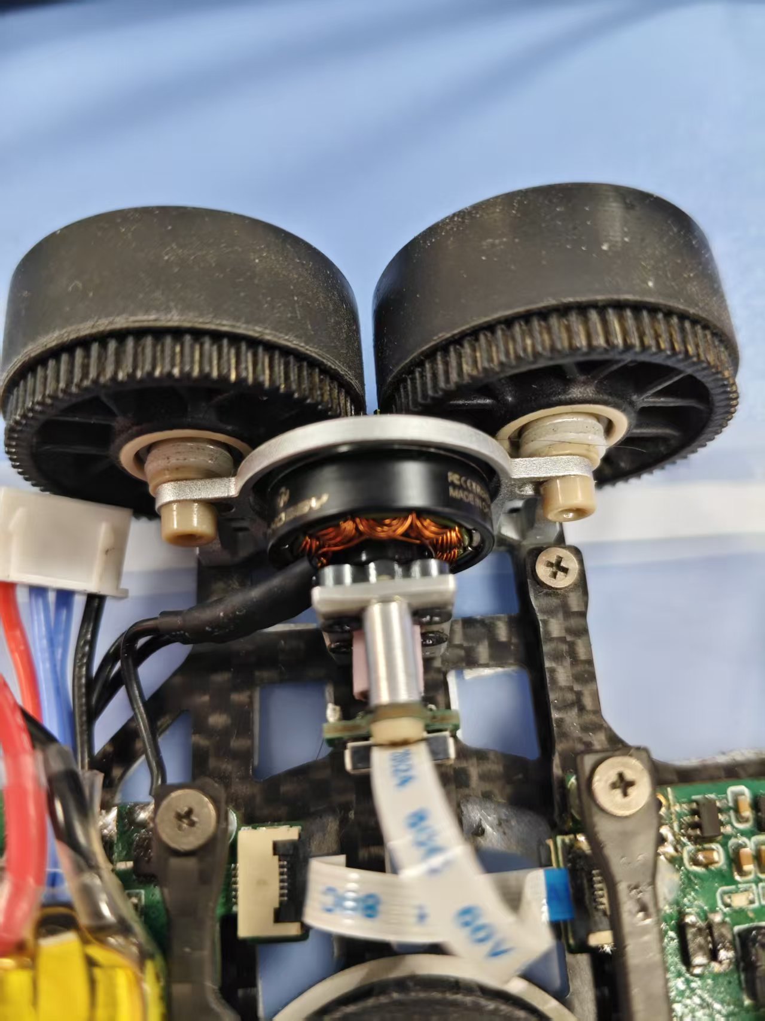
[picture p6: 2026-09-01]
images/f2cc383ff80ecda33a6a4c25bd8d2225.jpg

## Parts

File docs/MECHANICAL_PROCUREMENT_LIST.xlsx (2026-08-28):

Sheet: 采购清单
纯惯导车机械采购与加工清单
默认配置：纯惯导 v4.0.3 / 加强茎 v7.0.0 / 1:5 减速比；下单前以“在售核验 / 下单规格”列和最终商品页为准。
操作提示：使用筛选查看类别；购买链接可直接点击打开；“已采购”列可手动填写 否 / 是 / 已下单。可选件不要与默认配置重复下单。
序号 | 类别 | 物料名称 | 规格 | 材质 / 型号 | 数量 | 单位 | 用途 / 备注 | 已采购 | 购买链接 / 供应商 | 图纸 / 加工文件 | 在售核验 / 下单规格
1 | CNC 加工 | 主支撑加强筋 | 加强茎 v7.0.0；2 份 | 碳纤维板 | 2 | 份 | 纯惯导版本必做。原文件名“加强茎”沿用建模命名。 CNC 必须按图增加 M2 螺纹孔，并逐孔试装确认。 | 否 | 淘宝搜索“哈长伟”；按 STEP 文件 CNC 加工 | mechanical/step/加强茎v7.0.0.STEP
2 | CNC 加工 | 侧板 / 电机支撑 | 侧板 v3.2.6；2 份 | 碳纤维板 | 2 | 份 | 必做；电机支撑。以 STEP 文件为加工依据。 CNC 必须按图增加 M2 螺纹孔，并逐孔试装确认。 | 否 | 浏览器搜索“铨洲”；按 STEP 文件 CNC 加工 | mechanical/step/侧板v3.2.6.STEP
3 | CNC 加工 | 纯惯导车模底板 | 车模 v4.0.3；1 份 | 碳纤维板 | 1 | 份 | 纯惯导版本必做；搭配加强茎 v7.0.0。以 STEP 文件为加工依据。 CNC 必须按图增加 M2 螺纹孔，并逐孔试装确认。 | 否 | 淘宝搜索“哈长伟”；按 STEP 文件 CNC 加工 | mechanical/step/车模v4.0.3.STEP
4 | CNC 加工 | 边板 / 轮毂支撑 | 边板2 v2.3.5；2 份 | 碳纤维板 | 2 | 份 | 必做；轮毂支撑。以 STEP 文件为加工依据。 CNC 必须按图增加 M2 螺纹孔，并逐孔试装确认。 | 否 | 浏览器搜索“铨洲”；按 STEP 文件 CNC 加工 | mechanical/step/边板2v2.3.5.STEP
5 | 3D 打印 | 轮毂齿轮 | 齿轮 v1.3.1；1:5 减速比；配套小齿轮为 0.5 模 10 齿；2 份 | PA12S | 2 | 份 | 纯惯导当前 1:5 配置；推荐嘉立创 PA12S。 | 否 | 嘉立创 3D 打印 PA12S；上传对应 STEP 文件 | mechanical/step/齿轮v1.3.1.STEP | 与 0.5 模 10 齿黄铜小齿轮配套。
6 | 3D 打印 | 磁铁固定件 | 粘胶 v7；2 份 | PLA + PETG | 2 | 份 | 必做；原说明建议 PLA 与 PETG 双料打印。 | 否 | 自行 3D 打印；建议 PLA + PETG 双料打印 | mechanical/step/粘胶v7.STEP
7 | 可选 CNC 加工 | 光电管版本加强筋 | 加强茎 v6.1.1；2 份 | 碳纤维板 | 2 | 份 | 光电管车模版本；与纯惯导 v7.0.0 二选一。 CNC 必须按图增加 M2 螺纹孔，并逐孔试装确认。 | 否 | 淘宝搜索“哈长伟”；按 STEP 文件 CNC 加工 | mechanical/step/加强茎v6.1.1.STEP
8 | 可选 CNC 加工 | 光电管车模底板 | 车模 v3.9.5；1 份 | 碳纤维板 | 1 | 份 | 光电管车模版本；与纯惯导 v4.0.3 二选一，搭配加强茎 v6.1.1。 CNC 必须按图增加 M2 螺纹孔，并逐孔试装确认。 | 否 | 淘宝搜索“哈长伟”；按 STEP 文件 CNC 加工 | mechanical/step/车模v3.9.5.STEP
9 | 可选 3D 打印 | 轮毂齿轮 | 齿轮 v1.1.4；1:8.5 减速比；配套小齿轮为 0.4 模 8 齿；2 份 | PA12S | 2 | 份 | 普通 1:8.5 配置；与 1:5 齿轮二选一。 | 否 | 嘉立创 3D 打印 PA12S；上传对应 STEP 文件 | mechanical/step/齿轮v1.1.4.STEP | 与 0.4 模 8 齿黄铜小齿轮配套。
10 | 可选 3D 打印 | 电磁支架（方案 A） | 电磁支架 v1.0.0 | PLA | 1 | 份 | 仅电磁组需要，不属于纯惯导整车必做件。 | 否 | 自行 3D 打印 PLA | mechanical/step/电磁支架v1.0.0.STEP
11 | 可选 3D 打印 | 电磁支架（方案 B） | 电磁支架2 v1.0.0 | PLA | 1 | 份 | 仅电磁组需要；与方案 A 二选一。 | 否 | 自行 3D 打印 PLA | mechanical/step/电磁支架2v1.0.0.STEP
12 | 紧固件 | 平垫片 | M2 | PEEK | 10 | 片 | 下单选 M2【10个】。 | 否 | https://e.tb.cn/h.8mcCPRhR8r6Abf2?tk=67dST3um0aT |  | 已核验：在售、有货；包装数匹配。
13 | 紧固件 | 平垫片 | M2.5 | PEEK | 10 | 片 | 下单选 M2.5【10个】。 | 否 | https://e.tb.cn/h.8mcCPRhR8r6Abf2?tk=67dST3um0aT |  | 已核验：在售、有货；包装数匹配。
14 | 紧固件 | 盘头螺丝 | M2 x 10 mm | PEEK | 4 | 颗 | 需要 4 颗；下单选 M2*10，按单价购买 4 颗。 | 否 | https://e.tb.cn/h.8k9zIJYJO9kp8Hs?tk=jm5VT3ulzzo |  | 已核验：在售、有货。
15 | 紧固件 | 螺丝 | M2.5 x 6 mm | PEEK | 8 | 颗 | 需要 8 颗；下单选 M2.5*6[2只]，下单数量选 4。 | 否 | https://e.tb.cn/h.8mcyAufcbGLKcY3?tk=XZ90T3unac3 |  | 已核验：在售、有货。
16 | 紧固件 | 螺母 | M2 | PEEK | 4 | 颗 | 需要 4 颗；商品为 M2【2只】，下单数量选 2。 | 否 | https://e.tb.cn/h.8mczamPgTZqUGx8?tk=T7OHT3uNCEz |  | 已核验：在售、有货。
17 | 紧固件 | 垫片 | 内径 4 mm；外径 7 mm；厚 0.3 mm | POM | 1 | 份 | 下单选 4*7*0.3；最小包装为 500 个。 | 否 | https://e.tb.cn/h.8mXao0V9CyJaiyk?tk=JJL4T3upc49 |  | 已核验：在售；规格匹配，包装数大于需求。
18 | 紧固件 | 螺丝 | M2 x 10 mm | TA2 钛合金 | 10 | 颗 | 下单选 M2*10【10只】。 | 否 | https://e.tb.cn/h.8k9HQxnIM9sNRd8?tk=gbwHT3uguuB |  | 已核验：在售、有货；包装数匹配。
19 | 紧固件 | 螺丝 | M2 x 3 mm | TA2 钛合金 | 10 | 颗 | 下单选 M2*3【10只】。 | 否 | https://e.tb.cn/h.8k9HQxnIM9sNRd8?tk=gbwHT3uguuB |  | 已核验：在售、有货；包装数匹配。
20 | 紧固件 | 螺丝 | M2 x 4 mm | TA2 钛合金 | 10 | 颗 | 下单选 M2*4【10只】。 | 否 | https://e.tb.cn/h.8k9HQxnIM9sNRd8?tk=gbwHT3uguuB |  | 已核验：在售、有货；包装数匹配。
21 | 紧固件 | 螺丝 | M2 x 5 mm | TA2 钛合金 | 10 | 颗 | 下单选 M2*5【10只】。 | 否 | https://e.tb.cn/h.8k9HQxnIM9sNRd8?tk=gbwHT3uguuB |  | 已核验：在售、有货；包装数匹配。
22 | 紧固件 | 螺丝 | M2 x 3 mm | 碳钢 | 100 | 颗 | 按 M2 x 3 mm 处理 | 否 | https://e.tb.cn/h.8PkU8AL21aKIX46?tk=FnisT3uELki |  | 已核验：在售；选 M2*3（100 个装）。
23 | 紧固件 | 螺丝 | M2 x 4 mm | 碳钢 | 100 | 颗 |  | 否 | https://e.tb.cn/h.8PkU8AL21aKIX46?tk=FnisT3uELki |  | 已核验：在售；选 M2*4（100 个装）。
24 | 紧固件 | 半圆头内六角螺丝 | M2 x 6 mm | 铝合金 | 2 | 颗 |  | 否 | https://e.tb.cn/h.8mXeBmJXwCWEfkR?tk=2YwvT3uFI8e |  | 已核验：在售；选 M2*6，商品为 2 个装。
25 | 紧固件 | 铝柱 | M2 x 3.5 mm | 铝合金 | 10 | 颗 | 下单选 M2*3.5-D=3.5MM（10支）。 | 否 | https://e.tb.cn/h.8mcJbt6WjCP0JSy?tk=iGsAT3uTzSu |  | 已核验：在售、有货；规格与 10 支包装匹配。
26 | 紧固件 | 铝柱 | M2 x 5 mm | 铝合金 | 10 | 颗 | 下单选 M2*5-D=3.5MM（10支）。 | 否 | https://e.tb.cn/h.8mcJbt6WjCP0JSy?tk=iGsAT3uTzSu |  | 已核验：在售、有货；规格与 10 支包装匹配。
27 | 紧固件 | 铝柱 | M2 x 6.8 mm | 铝合金 | 10 | 颗 | 下单选 M2*6.8-D=3.5MM（10支）。 | 否 | https://e.tb.cn/h.8mcJbt6WjCP0JSy?tk=iGsAT3uTzSu |  | 已核验：在售、有货；规格与 10 支包装匹配。
28 | 紧固件 | 铝柱 | M2.5 x 15 mm | 铝合金 | 10 | 颗 | 下单选 M2.5x15（D4），10 支。 | 否 | https://e.tb.cn/h.8k9GsYJvXbqWoei?tk=fEgjT3uh7nR |  | 已核验：在售、有货；规格与 10 支包装匹配。
29 | 减振 | 橡胶垫片 | 内径 2 mm；外径 5 mm；厚 1.5 mm | 橡胶 | 20 | 颗 | 下单选 2*5*1.5（20只）。 | 否 | https://e.tb.cn/h.8lpP91xfSjr0gZL?tk=kItUT3uptxv |  | 已核验：在售、有货；规格与数量匹配。
30 | 减振 | 聚氨酯海绵 | 待按安装尺寸裁切 | 聚氨酯 | 1 | 份 | 用于 PCB/IMU 减振 | 否 | https://e.tb.cn/h.8lpkXIzQXcTAgRS?tk=cteeT3uL62O
31 | 传动 | 编码器径向充磁磁铁 | 圆形径向充磁；尺寸待按编码器型号确认 | N35 钕铁硼，镍镀层 | 4 | 个 | 四轮编码器各 1 个；安装磁铁与编码器的实际间距约 1 mm。 | 否 | https://e.tb.cn/h.8mBtW10luYOM3fO?tk=Exr9TeJeSW9 |  | 已核验：在售、有货；可选 10/20/50/100 个装。下单前必须确认直径和厚度，勿按起价直接购买。
32 | 传动 | 轴承 | 内径 4 mm；外径 11 mm；厚 4 mm | PEEK 或同尺寸替代 | 8 | 颗 | 轮毂轴承；下单选 PEEK694（内径 4 mm、外径 11 mm、厚 4 mm）。 | 否 | https://e.tb.cn/h.8mcxILEdGMrRZHv?tk=NkVrT3uOocV |  | 已核验：在售、有货；规格 PEEK694 完全匹配。
33 | 传动 | 黄铜齿轮 | 1:5 减速比配套；0.5 模，10 齿 | 黄铜 | 2 | 颗 |  | 否 | https://e.tb.cn/h.8mXUdcSt3XmXSnl?tk=1mKJT3uEBDK |  | 已核验：在售；选 10 齿。轴孔有 1.45/1.95/2.25/2.95 mm，按电机轴径选择。
34 | 传动 | 黄铜齿轮（1:8.5 配套） | 1:8.5 减速比配套；0.4 模，8 齿 | 黄铜 | 2 | 颗 | 与 1:5 的 0.5 模 10 齿齿轮二选一。 | 否 | https://e.tb.cn/h.8mXU98qGpzvzAW9?tk=36ViT3uwCD4 |  | 已核验：在售；选 8 齿、外径 4 mm、孔 1.48 mm、厚 4 mm。
35 | 轮胎 | 龙邱 N 车模胎皮 | 龙邱 N 车模规格 |  | 4 | 个 | 下单选“闪电鼠-N超软硅胶轮胎”，数量 4。 | 否 | https://e.tb.cn/h.8P9t6THlsmDb02D?tk=3HiqT3u72p8 |  | 已核验：预售，约 5 天发货。
36 | 行进 | 无刷电机 | T-Motor F1404，3800 KV |  | 2 | 颗 | 行进电机；下单选 3800KV、一颗装。 | 否 | https://e.tb.cn/h.8mX8okkLmuej62t?tk=hs43T3F0tV7 |  | 已核验：在售、有货。
37 | 负压 | 无刷电机 | 致盈动力 GTS V2 1202.5，6000 KV |  | 1 | 颗 | 负压电机；下单选 6000KV【3-4S】一个装。 | 否 | https://e.tb.cn/h.8mXRO5DbPoWJfw9?tk=By03T3F0om4 |  | 已核验：在售、有货；商品型号为 GTS V2 1202.5。
38 | 负压 | 负压膜 | 晨光书皮 |  | 1 | 份 |  | 否 | https://e.tb.cn/h.8mX0D4OeRIXlw04?tk=ocbqT3uqjSP
39 | 负压 | 风机 | 龙邱 1202.5 尼龙无刷离心风机 |  | 1 | 份 | 下单选“1202.5 尼龙无刷离心风机”，不要误选负压无刷电机。 | 否 | https://e.tb.cn/h.8PkSTi588UCBtaw?tk=dKFCT3uBW81 |  | 已核验：在售；同一链接同时售风机、电机和软膜。
40 | 粘接 | 双面胶 | 3M 9495 |  | 1 | 卷 | 用于贴负压 | 否 | https://e.tb.cn/h.8lp7YVn7C9ZhFWG?tk=GcDuT3ulg6z
41 | 粘接 | 双面胶 | 3M VHB |  | 1 | 卷 | 用于需方便拆除的粘接部位 | 否 | https://e.tb.cn/h.8mcD9pQHB3meS3g?tk=mwmQT3ulk7c

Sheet: 汇总
采购执行概览
传动 | 2 | 先按类别，再按材质，同种物料规格相邻排列。加工件增加“图纸 / 加工文件”列；购买渠道填写在“购买链接 / 供应商”列。
总条目 |  | 按物料条目统计
已下单 |  | 按物料条目统计
已采购 |  | 按物料条目统计
待采购 |  | 按物料条目统计
负压 | 3 | 按物料条目统计
状态图例
否：尚未采购
已下单：等待收货
是：已采购
默认整车加工配置：纯惯导车模 v4.0.3、加强茎 v7.0.0、1:5 齿轮 v1.3.1。
光电管车模、1:8.5 齿轮和电磁支架已标为可选，不应与默认版本重复下单。
CNC 加工要求：所有需螺丝固定的 CNC 件必须按图增加 M2 螺纹孔，不能只留光孔；加工后逐孔试装确认。
加工购买方式：边板/侧板搜“铨洲”；车模/加强茎搜“哈长伟”；齿轮由嘉立创按 PA12S 打印；粘胶和电磁支架自行 3D 打印。
链接核验说明：2026-08-27 已通过淘宝商品详情页核验；“有货/预售”仅代表核验时页面状态，最终以下单页为准。
费用估算与免责说明
预计总开销：约 600 元，不含轴承。该数字是当前清单的粗略预算，不是报价或费用承诺；实际价格、运费、加工费和材料损耗会随渠道与版本变化。
其中：CNC 加工 + 碳板 + 3D 打印约 250 元出头；三颗电机约 250 元；零散紧固件、胶带、垫片、胎皮等物料约 100 多元。
本清单和机械资料仅用于设计参考与学习，不保证适配每一块场地、每一批材料或每种加工工艺，也不构成安全、性能或可制造性担保。
如有经济压力，可以将底盘、传动、负压、传感器安装等拆分为多个模块自行设计和验证；欢迎参考设计思路，不建议完全机械复刻。
涉及高速电机、负压、刀具和 CNC/3D 打印加工时，请自行完成强度、干涉、电气和安全验证，并从低速、架空测试开始。

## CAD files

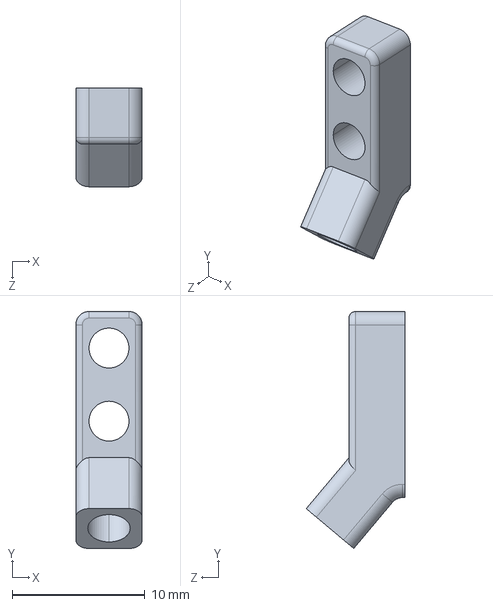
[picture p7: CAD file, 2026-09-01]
mechanical/step/电磁支架v1.0.0.STEP
5.00 x 17.8 x 7.41 mm

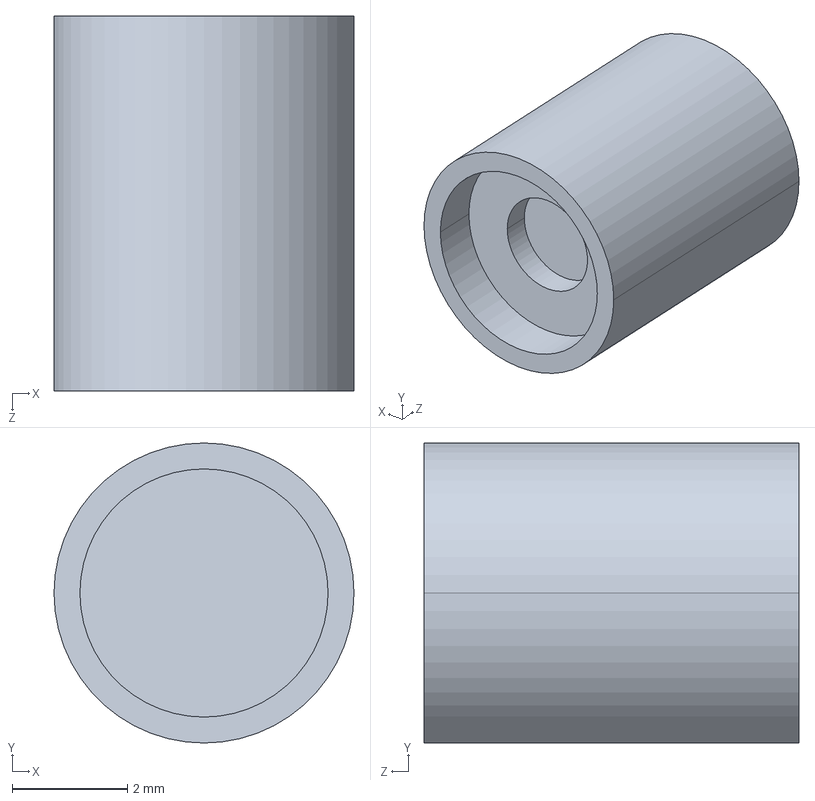
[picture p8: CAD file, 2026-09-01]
mechanical/step/粘胶v7.STEP
5.20 x 5.20 x 6.50 mm

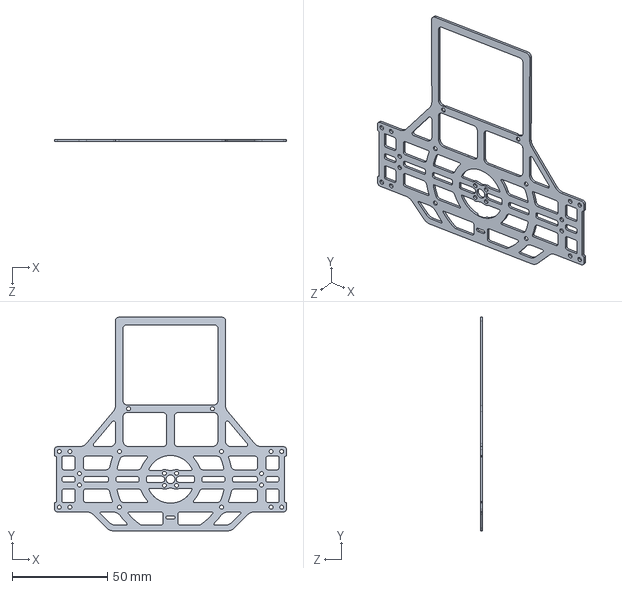
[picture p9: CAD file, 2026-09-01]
mechanical/step/车模v4.0.3.STEP
121.6 x 112.0 x 1.20 mm

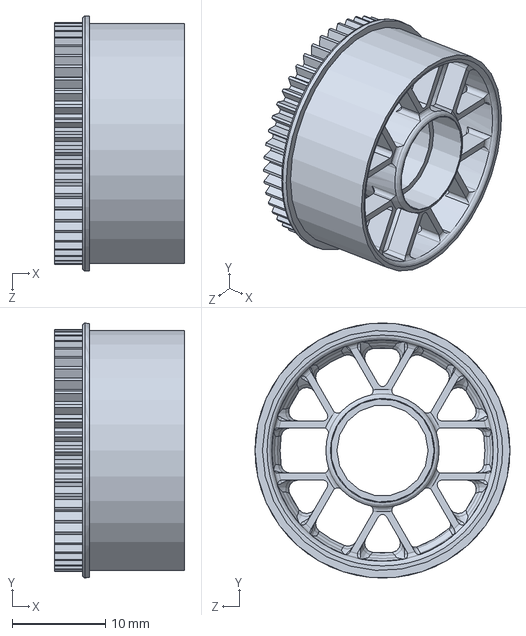
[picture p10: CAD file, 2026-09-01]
mechanical/sldprt/齿轮v1.3.0.SLDPRT
14.0 x 27.4 x 27.4 mm

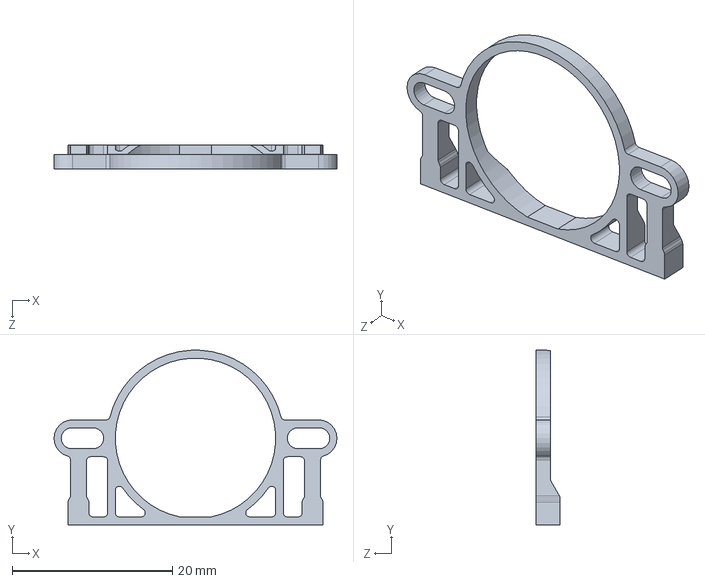
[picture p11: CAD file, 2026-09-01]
mechanical/sldprt/边板2v2.3.0.SLDPRT
35.3 x 21.8 x 3.00 mm

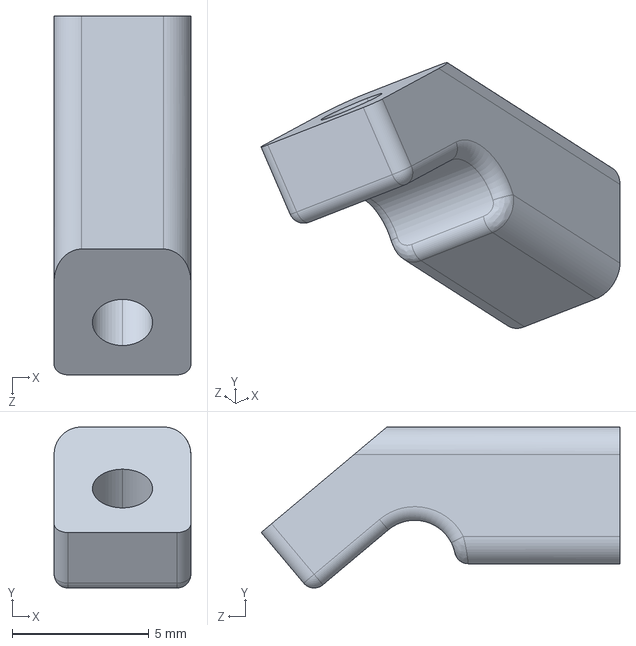
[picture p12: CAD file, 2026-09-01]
mechanical/step/电磁支架2v1.0.0.STEP
5.00 x 5.89 x 13.1 mm

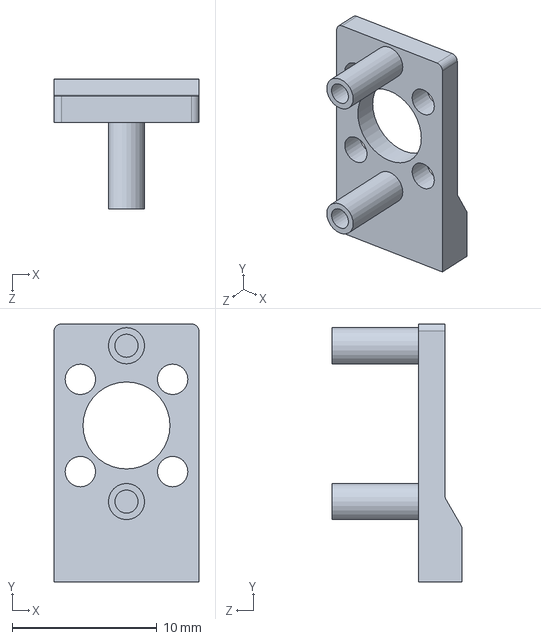
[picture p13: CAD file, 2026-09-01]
mechanical/sldprt/侧板v3.2.0.SLDPRT
10.0 x 17.8 x 9.00 mm

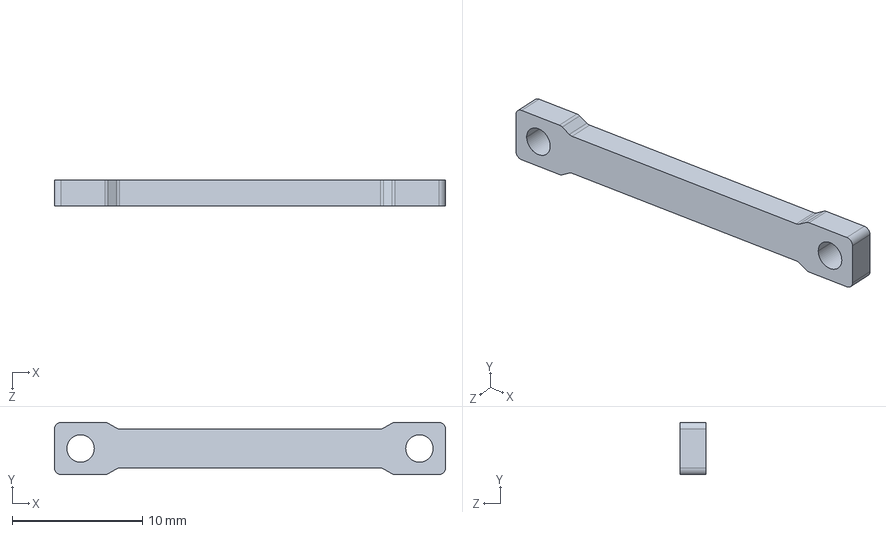
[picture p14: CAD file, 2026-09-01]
mechanical/step/加强茎v7.0.0.STEP
30.0 x 4.00 x 2.00 mm

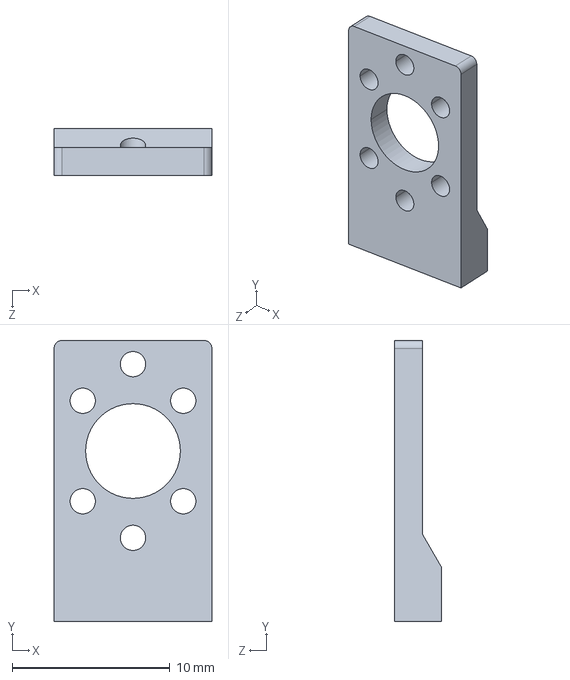
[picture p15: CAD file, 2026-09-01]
mechanical/step/侧板v3.2.6.STEP
10.0 x 17.8 x 3.00 mm

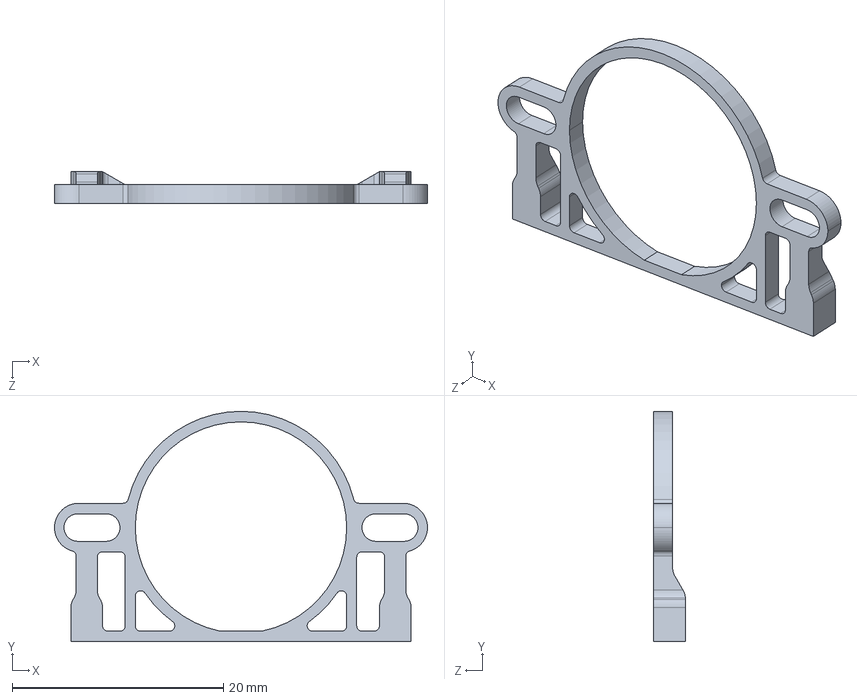
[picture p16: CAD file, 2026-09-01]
mechanical/step/边板2v2.3.5.STEP
35.3 x 21.8 x 3.00 mm

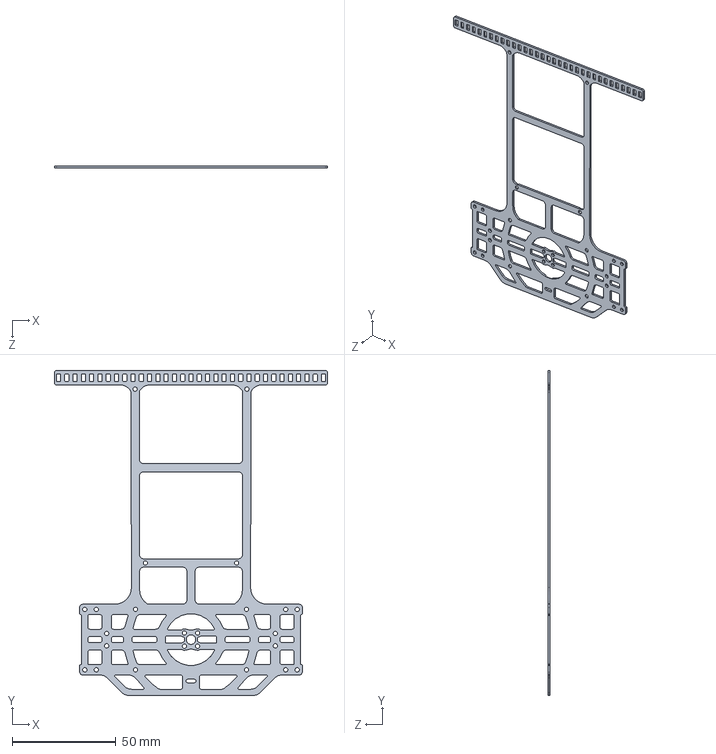
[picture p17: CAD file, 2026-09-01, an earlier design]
mechanical/sldprt/车模v3.9.0.SLDPRT
132.0 x 157.0 x 1.20 mm

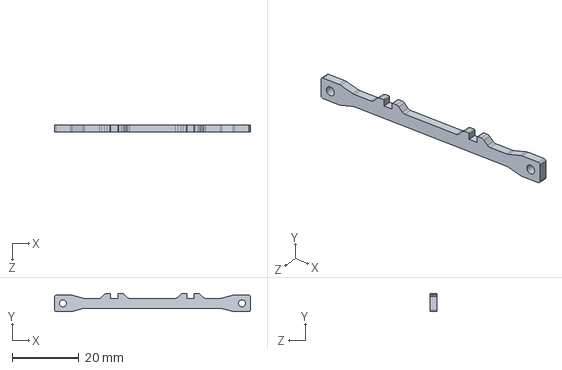
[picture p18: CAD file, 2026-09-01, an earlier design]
mechanical/sldprt/加强茎v3.0.0.SLDPRT
58.6 x 5.50 x 2.00 mm

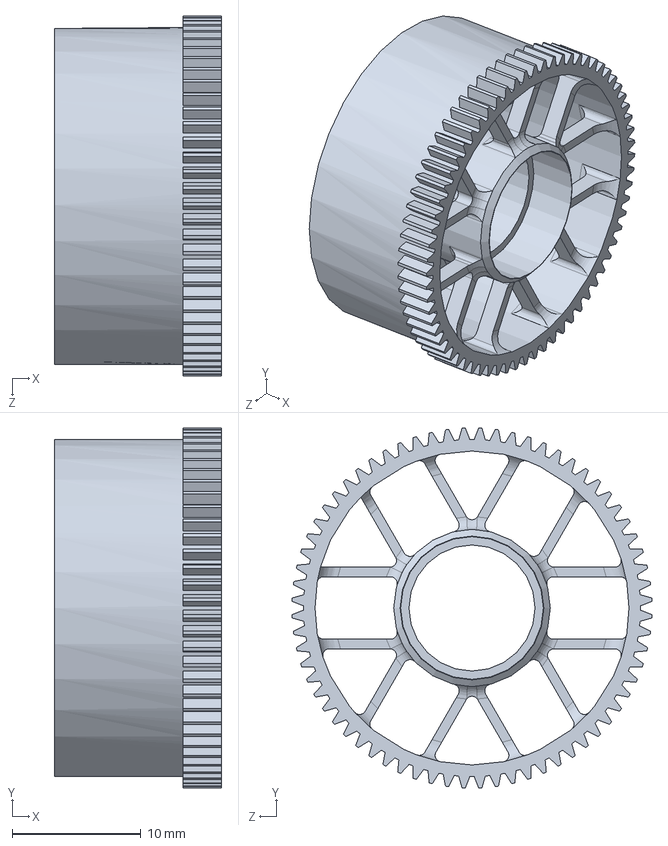
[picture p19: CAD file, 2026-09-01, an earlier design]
mechanical/sldprt/齿轮v1.2.0.SLDPRT
13.0 x 28.0 x 28.0 mm

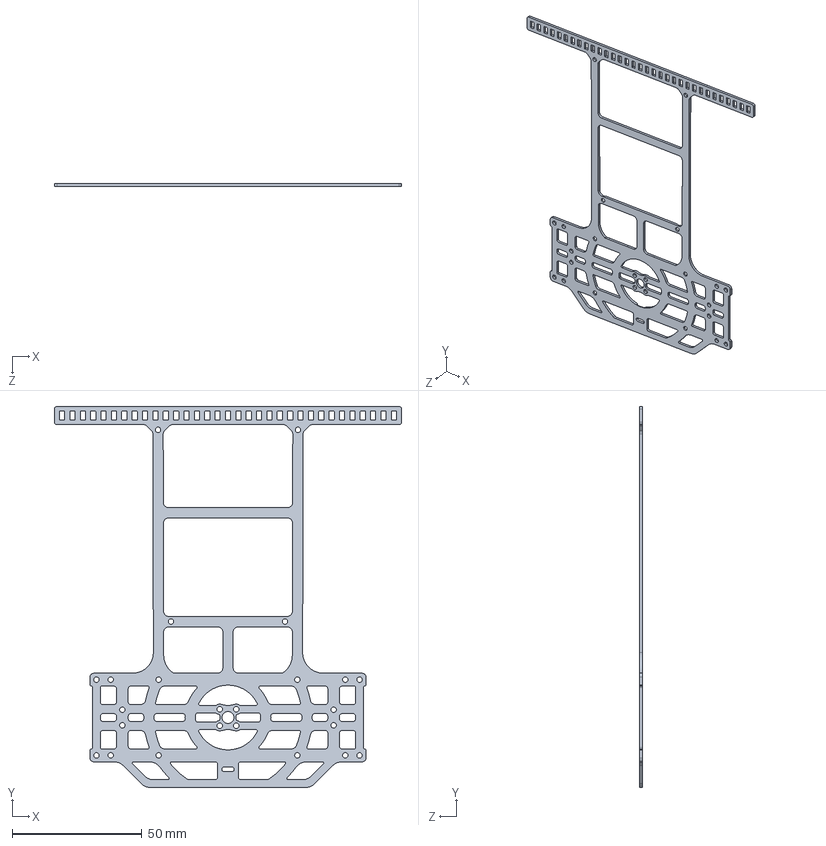
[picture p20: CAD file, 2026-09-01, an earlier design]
mechanical/step/车模v3.9.5.STEP
134.0 x 147.0 x 1.20 mm

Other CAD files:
mechanical/sldprt/磁铁套.SLDPRT
mechanical/step/齿轮v1.3.1.STEP
mechanical/step/加强茎v3.1.0.STEP
mechanical/sldprt/加强茎v6.0.0.SLDPRT
mechanical/sldprt/加强茎v7.0.0.SLDPRT
mechanical/sldprt/车模v4.0.3.SLDPRT
mechanical/sldprt/齿轮v1.1.0.SLDPRT
mechanical/step/加强茎v3.0.1.STEP
mechanical/step/加强茎v6.1.1.STEP
mechanical/step/齿轮v1.1.4.STEP

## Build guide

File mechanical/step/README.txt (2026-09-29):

齿轮v1.1.4是普通版1：8.5齿轮
齿轮v1.3.1是普通版1：5齿轮

加强茎v3.1.0与加强茎v3.1.0为必打加强筋，用于主支撑
电磁支架2v1.0.0与电磁支架v1.0.0为3d打印件，是电磁组的，我用的是pla

车模v3.9.5是光电管车模，搭配加强茎v6.1.1
车模v4.0.3是纯导车模，搭配加强茎v7.0.0
粘胶v7为磁铁固定件，必打

边板2v2.3.5为轮毂支撑，必打
侧板v3.2.6为电机支撑，必打

如果要拼凑出一辆车，需要：
2份：边板2v2.3.5（浏览器搜铨洲）   侧板v3.2.6（浏览器搜铨洲）  粘胶v7（pla与petg3d双料打印最好）  加强茎v6.1.1或加强茎v7.0.0 （淘宝搜哈长伟）  齿轮v1.3.1或齿轮v1.1.4（嘉立创3d打印的PA12S）
1份：车模v3.9.5或车模v4.0.3（淘宝搜哈长伟） 

ps：别问为什么是加强茎而不是加强筋，问就是懒得换（

电机小边板一定要打螺纹孔，一定要打螺纹孔，一定要打螺纹孔。

复刻一定要先阅读机械采购与加工清单（Excel）完整内容。

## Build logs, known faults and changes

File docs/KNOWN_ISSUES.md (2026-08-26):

# 已知问题与验证状态

更新日期：2026-08-26。

## 已通过

- `software/tools/path-tools/tools/test_amr_path_viewer.js`
- `software/tools/path-tools/tools/test_node_radius_cdp.js`
- `software/tools/PathCapture/tests/test_command_templates.js`

## 需要处理

### 节点规划器浏览器测试

`software/tools/path-tools/tools/test_node_coordinate_viewer.js` 在当前 Node.js 22 + CDP 环境中加载页面脚本时出现 `SyntaxError: Invalid or unexpected token`，测试尚未进入功能断言。公开发布前应定位并修复该页面脚本的解析问题，然后重新运行完整测试。

### PathCapture Python 测试环境

`pytest` 在当前系统 Python 环境中未找到 `flask`，因此无法收集 `test_parser.py` 和 `test_binary_telemetry.py`。这不是已确认的功能失败；请先在 `software/tools/PathCapture/` 下运行 `launch.bat`，或创建虚拟环境并执行 `pip install -r requirements.txt`，再运行测试。

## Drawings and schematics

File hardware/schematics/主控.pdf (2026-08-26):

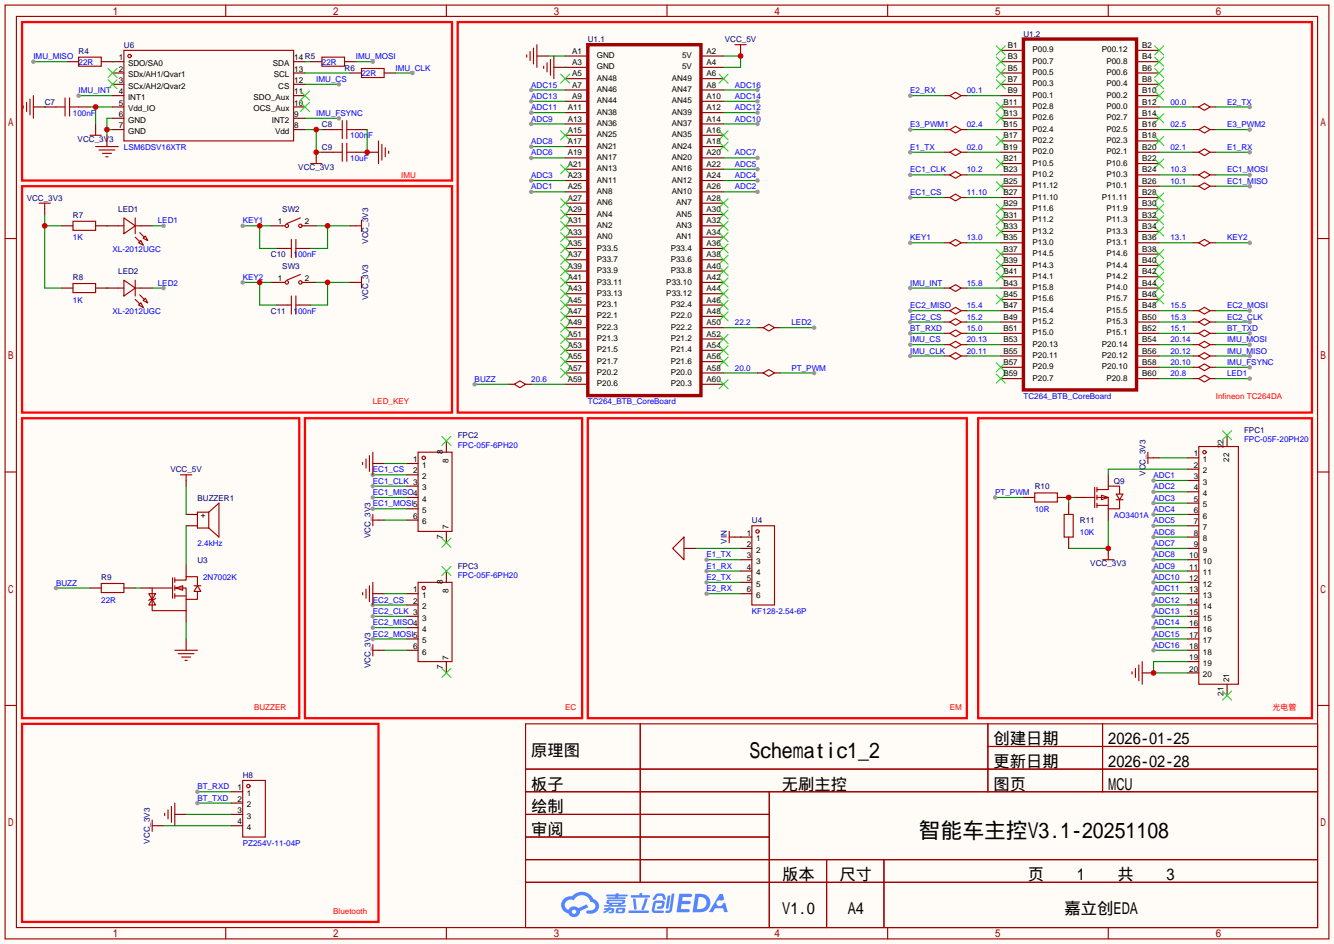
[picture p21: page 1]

原理图 | Schematic1_2 | 创建日期 | 2026-01-25

更新日期 | 2026-02-28

板子 | 无刷主控 | 图页 | MCU
绘制 | | 智能车主控V3.1-20251108
审阅

V1.0 | A4 | 嘉立创EDA

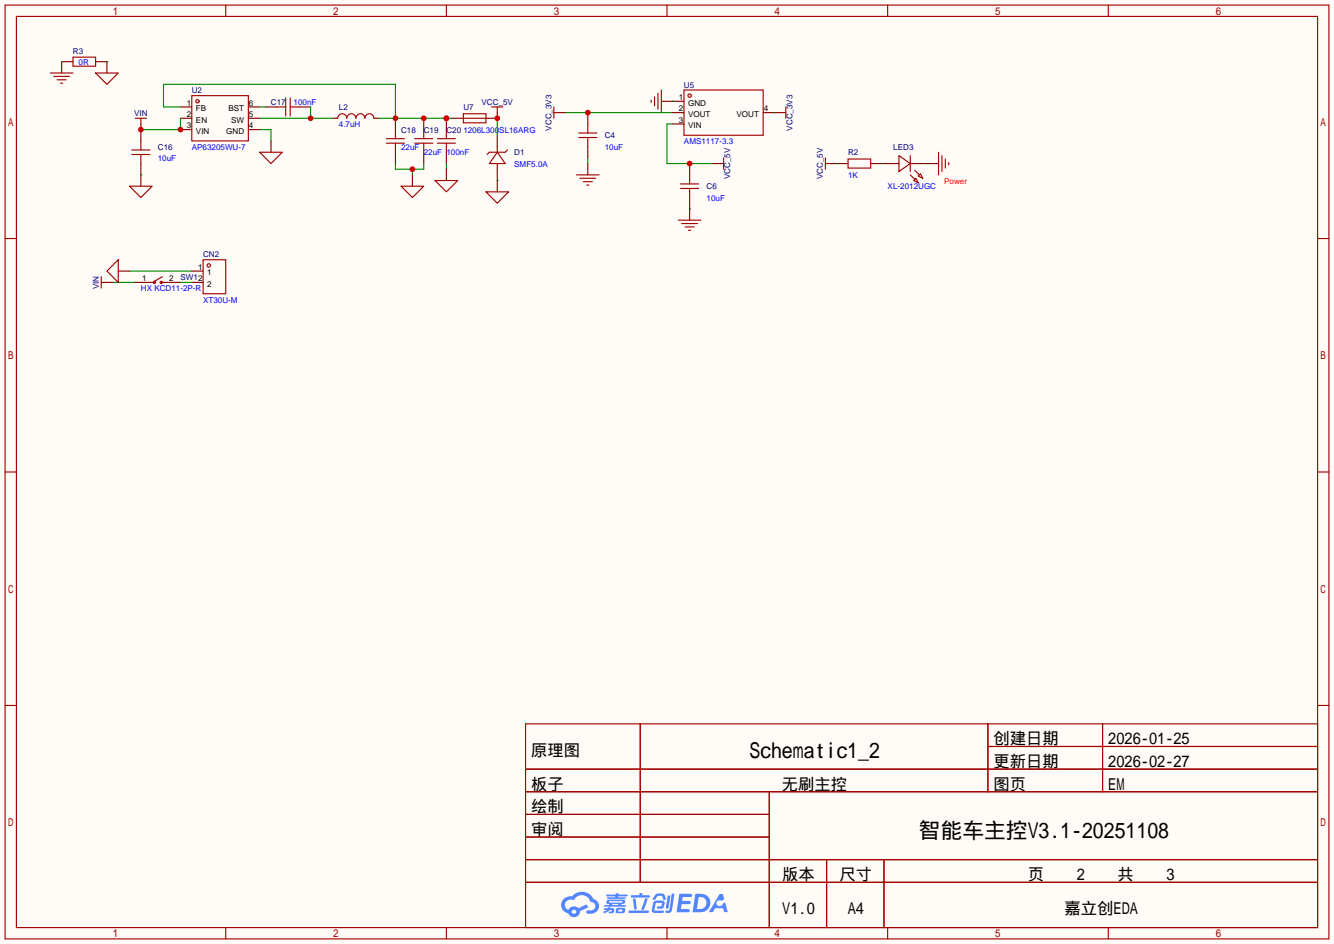
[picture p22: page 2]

原理图 | Schematic1_2 | 创建日期 | 2026-01-25

更新日期 | 2026-02-27

板子 | 无刷主控 | 图页 | EM
绘制 | | 智能车主控V3.1-20251108
审阅

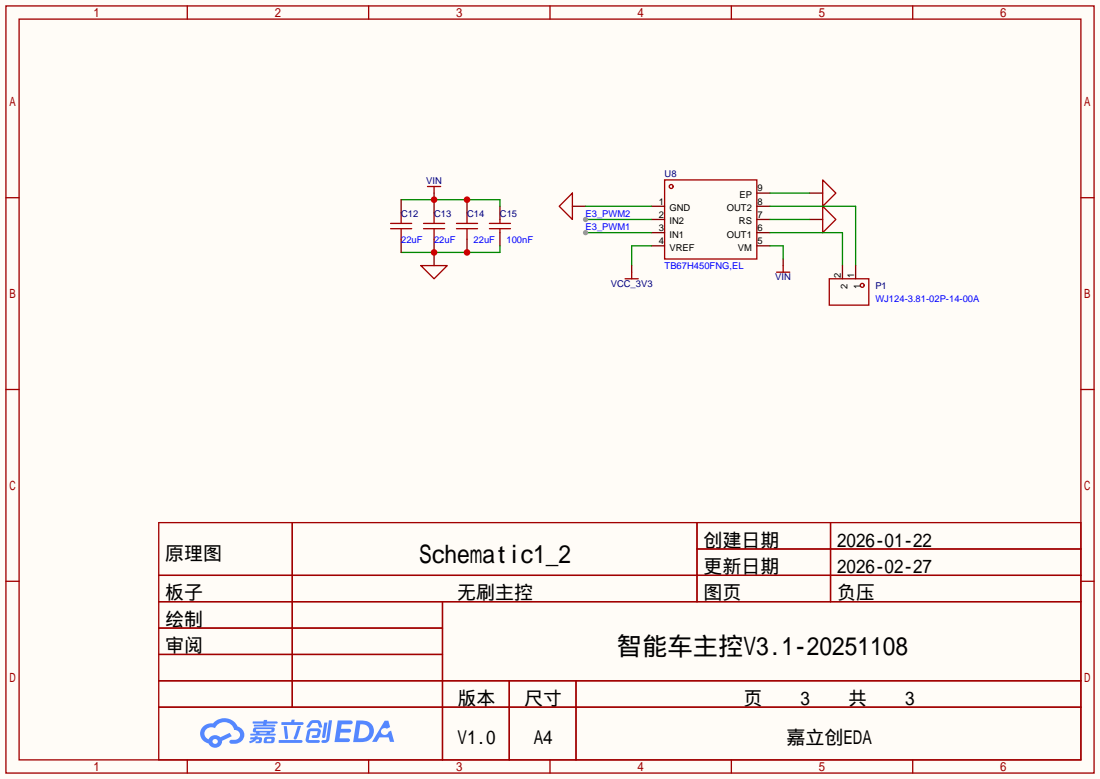
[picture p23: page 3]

原理图 | Schematic1_2 | 创建日期 | 2026-01-22

更新日期 | 2026-02-27

板子 | 无刷主控 | 图页 | 负压
绘制 | | 智能车主控V3.1-20251108
审阅

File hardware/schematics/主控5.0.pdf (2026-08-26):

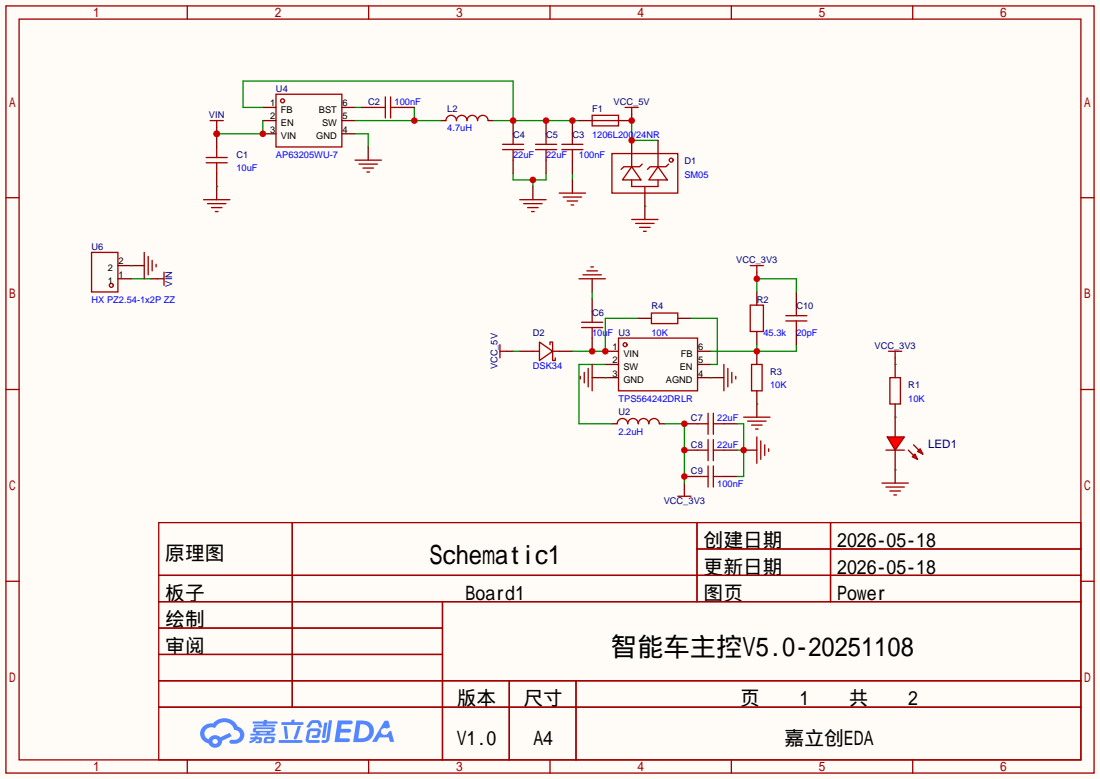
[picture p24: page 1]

原理图 | Schematic1 | 创建日期 | 2026-05-18

更新日期 | 2026-05-18

板子 | Board1 | 图页 | Power
绘制 | | 智能车主控V5.0-20251108
审阅

V1.0 | A4 | 嘉立创EDA

# ADC13 1

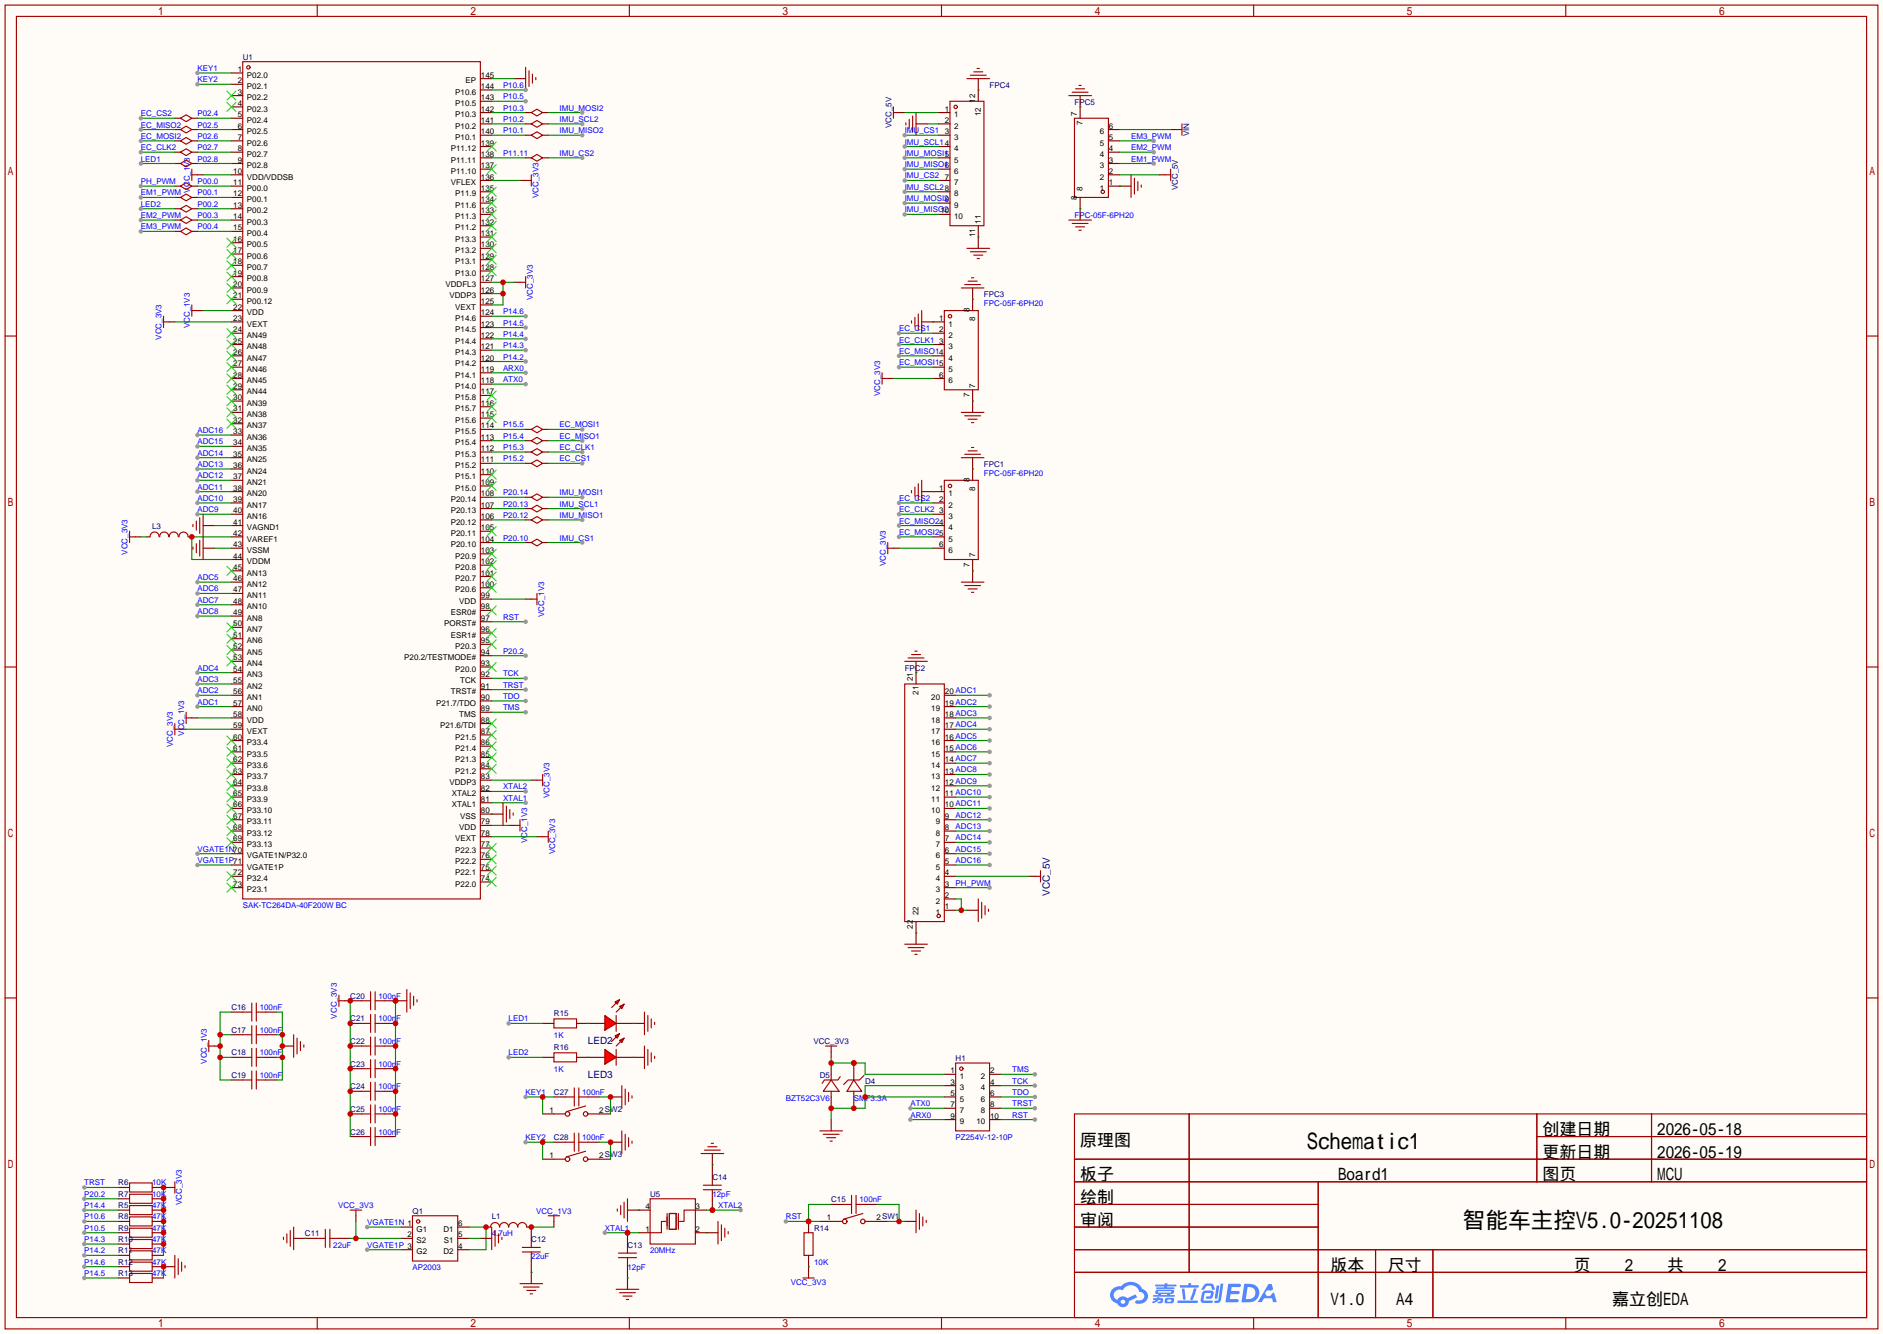
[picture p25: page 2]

原理图 | Schematic1 | 创建日期 | 2026-05-18

更新日期 | 2026-05-19

板子 | Board1 | 图页 | MCU

V1.0 | A4 | 嘉立创EDA

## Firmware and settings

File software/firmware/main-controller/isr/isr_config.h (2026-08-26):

#ifndef MAD_CIRCUITS_ISR_CONFIG_H
#define MAD_CIRCUITS_ISR_CONFIG_H

#include "IfxSrc_cfg.h"

#define ISR_CONFIG_PRIORITY_DEBUG_TX_BUSINESS_INTERRUPT 2
#define ISR_CONFIG_PRIORITY_DEBUG_RX_BUSINESS_INTERRUPT 1

#define ISR_CONFIG_PRIORITY_ESC_UART_TX_BUSINESS_INTERRUPT 22

#define ISR_CONFIG_PRIORITY_IMU1_BUSINESS_INTERRUPT 41
#define ISR_CONFIG_PRIORITY_IMU2_BUSINESS_INTERRUPT 40
#define ISR_CONFIG_PRIORITY_MAGNETIC_ENCODER1_BUSINESS_INTERRUPT 39
#define ISR_CONFIG_PRIORITY_MAGNETIC_ENCODER2_BUSINESS_INTERRUPT 38

#define ISR_CONFIG_PRIORITY_PHOTOTUBE_SWITCH_BUSINESS_INTERRUPT 37
#define ISR_CONFIG_PRIORITY_PHOTOTUBE_GROUP0_BUSINESS_INTERRUPT 35
#define ISR_CONFIG_PRIORITY_PHOTOTUBE_GROUP1_BUSINESS_INTERRUPT 27
#define ISR_CONFIG_PRIORITY_PHOTOTUBE_GROUP2_BUSINESS_INTERRUPT 21

#define ISR_CONFIG_PRIORITY_TASK1_BUSINESS_INTERRUPT 19
#define ISR_CONFIG_PRIORITY_TASK2_BUSINESS_INTERRUPT 18
#define ISR_CONFIG_PRIORITY_TASK3_BUSINESS_INTERRUPT 17
#define ISR_CONFIG_PRIORITY_TASK4_BUSINESS_INTERRUPT 16
#define ISR_CONFIG_PRIORITY_TASK5_BUSINESS_INTERRUPT 15
#define ISR_CONFIG_PRIORITY_TASK6_BUSINESS_INTERRUPT 14
#define ISR_CONFIG_PRIORITY_TASK7_BUSINESS_INTERRUPT 13
#define ISR_CONFIG_PRIORITY_TASK8_BUSINESS_INTERRUPT 12

#define ISR_CONFIG_PRIORITY_SYSTICK1_BUSINESS_INTERRUPT 20

#define ISR_CONFIG_PRIORITY_CARRIER1_BUSINESS_INTERRUPT 10
#define ISR_CONFIG_PRIORITY_CARRIER2_BUSINESS_INTERRUPT 9
#define ISR_CONFIG_PRIORITY_CARRIER3_BUSINESS_INTERRUPT 8
#define ISR_CONFIG_PRIORITY_CARRIER4_BUSINESS_INTERRUPT 7
#define ISR_CONFIG_PRIORITY_CARRIER5_BUSINESS_INTERRUPT 6
#define ISR_CONFIG_PRIORITY_CARRIER6_BUSINESS_INTERRUPT 5
#define ISR_CONFIG_PRIORITY_CARRIER7_BUSINESS_INTERRUPT 4
#define ISR_CONFIG_PRIORITY_CARRIER8_BUSINESS_INTERRUPT 3

#define ISR_CONFIG_VECTABNUM_DEBUG_TX_BUSINESS_INTERRUPT 0
#define ISR_CONFIG_VECTABNUM_DEBUG_RX_BUSINESS_INTERRUPT 0

#define ISR_CONFIG_VECTABNUM_ESC_UART_TX_BUSINESS_INTERRUPT 0

#define ISR_CONFIG_VECTABNUM_IMU1_BUSINESS_INTERRUPT 0
#define ISR_CONFIG_VECTABNUM_IMU2_BUSINESS_INTERRUPT 0
#define ISR_CONFIG_VECTABNUM_MAGNETIC_ENCODER1_BUSINESS_INTERRUPT 0
#define ISR_CONFIG_VECTABNUM_MAGNETIC_ENCODER2_BUSINESS_INTERRUPT 0

#define ISR_CONFIG_VECTABNUM_PHOTOTUBE_SWITCH_BUSINESS_INTERRUPT 0
#define ISR_CONFIG_VECTABNUM_PHOTOTUBE_GROUP0_BUSINESS_INTERRUPT 0
#define ISR_CONFIG_VECTABNUM_PHOTOTUBE_GROUP1_BUSINESS_INTERRUPT 0
#define ISR_CONFIG_VECTABNUM_PHOTOTUBE_GROUP2_BUSINESS_INTERRUPT 0

#define ISR_CONFIG_VECTABNUM_TASK1_BUSINESS_INTERRUPT 0
#define ISR_CONFIG_VECTABNUM_TASK2_BUSINESS_INTERRUPT 0
#define ISR_CONFIG_VECTABNUM_TASK3_BUSINESS_INTERRUPT 0
#define ISR_CONFIG_VECTABNUM_TASK4_BUSINESS_INTERRUPT 0
#define ISR_CONFIG_VECTABNUM_TASK5_BUSINESS_INTERRUPT 0
#define ISR_CONFIG_VECTABNUM_TASK6_BUSINESS_INTERRUPT 0
#define ISR_CONFIG_VECTABNUM_TASK7_BUSINESS_INTERRUPT 0
#define ISR_CONFIG_VECTABNUM_TASK8_BUSINESS_INTERRUPT 0

#define ISR_CONFIG_VECTABNUM_SYSTICK1_BUSINESS_INTERRUPT 0

#define ISR_CONFIG_VECTABNUM_CARRIER1_BUSINESS_INTERRUPT 0
#define ISR_CONFIG_VECTABNUM_CARRIER2_BUSINESS_INTERRUPT 0
#define ISR_CONFIG_VECTABNUM_CARRIER3_BUSINESS_INTERRUPT 0
#define ISR_CONFIG_VECTABNUM_CARRIER4_BUSINESS_INTERRUPT 0
#define ISR_CONFIG_VECTABNUM_CARRIER5_BUSINESS_INTERRUPT 0
#define ISR_CONFIG_VECTABNUM_CARRIER6_BUSINESS_INTERRUPT 0
#define ISR_CONFIG_VECTABNUM_CARRIER7_BUSINESS_INTERRUPT 0
#define ISR_CONFIG_VECTABNUM_CARRIER8_BUSINESS_INTERRUPT 0

#define ISR_CONFIG_TOS_DEBUG_TXRXER_BUSINESS_INTERRUPT IfxSrc_Tos_cpu0

#define ISR_CONFIG_TOS_ESC_UART_TX_BUSINESS_INTERRUPT IfxSrc_Tos_cpu0

#define ISR_CONFIG_TOS_IMU1_BUSINESS_INTERRUPT IfxSrc_Tos_cpu1
#define ISR_CONFIG_TOS_IMU2_BUSINESS_INTERRUPT IfxSrc_Tos_cpu1
#define ISR_CONFIG_TOS_MAGNETIC_ENCODER1_BUSINESS_INTERRUPT IfxSrc_Tos_cpu1
#define ISR_CONFIG_TOS_MAGNETIC_ENCODER2_BUSINESS_INTERRUPT IfxSrc_Tos_cpu1

#define ISR_CONFIG_TOS_PHOTOTUBE_SWITCH_BUSINESS_INTERRUPT IfxSrc_Tos_cpu0
#define ISR_CONFIG_TOS_PHOTOTUBE_GROUP0_BUSINESS_INTERRUPT IfxSrc_Tos_cpu0
#define ISR_CONFIG_TOS_PHOTOTUBE_GROUP1_BUSINESS_INTERRUPT IfxSrc_Tos_cpu0
#define ISR_CONFIG_TOS_PHOTOTUBE_GROUP2_BUSINESS_INTERRUPT IfxSrc_Tos_cpu0

#define ISR_CONFIG_TOS_TASK1_BUSINESS_INTERRUPT IfxSrc_Tos_cpu1
#define ISR_CONFIG_TOS_TASK2_BUSINESS_INTERRUPT IfxSrc_Tos_cpu0
#define ISR_CONFIG_TOS_TASK3_BUSINESS_INTERRUPT IfxSrc_Tos_cpu0
#define ISR_CONFIG_TOS_TASK4_BUSINESS_INTERRUPT IfxSrc_Tos_cpu0
#define ISR_CONFIG_TOS_TASK5_BUSINESS_INTERRUPT IfxSrc_Tos_cpu0
#define ISR_CONFIG_TOS_TASK6_BUSINESS_INTERRUPT IfxSrc_Tos_cpu0
#define ISR_CONFIG_TOS_TASK7_BUSINESS_INTERRUPT IfxSrc_Tos_cpu0
#define ISR_CONFIG_TOS_TASK8_BUSINESS_INTERRUPT IfxSrc_Tos_cpu0

#define ISR_CONFIG_TOS_SYSTICK1_BUSINESS_INTERRUPT IfxSrc_Tos_cpu1
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

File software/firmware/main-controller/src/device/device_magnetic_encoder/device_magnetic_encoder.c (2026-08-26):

/**
 * @file device_magnetic_encoder.c
 * @brief 磁编码器设备对外调用接口实现。
 */

#include "../../../inc/device/device_magnetic_encoder/device_magnetic_encoder.h"
#include "../../../config/device/device_magnetic_encoder/device_magnetic_encoder_register.h"

IFX_INLINE uint16 device_magnetic_encoder_command_build(device_magnetic_encoder_register_t register_address, boolean is_read);
IFX_INLINE uint16 device_magnetic_encoder_parity_append(uint16 value);
IFX_INLINE uint16 device_magnetic_encoder_read_register(device_magnetic_encoder_id_t magnetic_encoder_id,
                                                    device_magnetic_encoder_register_t register_address);
IFX_INLINE void device_magnetic_encoder_write_register(device_magnetic_encoder_id_t magnetic_encoder_id,
                                                   device_magnetic_encoder_register_t register_address,
                                                   uint16 value);

/**
 * @brief 初始化指定磁编码器设备。
 * @param[in] magnetic_encoder_id 磁编码器设备编号。
 * @return void
 */
void device_magnetic_encoder_init(device_magnetic_encoder_id_t magnetic_encoder_id)
{
    device_magnetic_encoder_cfg_t* magnetic_encoder_cfg = device_magnetic_encoder_cfg_table_get();
    device_magnetic_encoder_runtime_t* magnetic_encoder_runtime = device_magnetic_encoder_runtime_table_get();

    driver_gtm_atom_timer_init(&magnetic_encoder_cfg[magnetic_encoder_id].gtm_atom_timer_cfg,
                               &magnetic_encoder_runtime[magnetic_encoder_id].gtm_atom_timer_runtime);
    driver_dma_init(&magnetic_encoder_cfg[magnetic_encoder_id].tx_dma_cfg,
                    &magnetic_encoder_runtime[magnetic_encoder_id].tx_dma_runtime);
    driver_qspi_init(&magnetic_encoder_cfg[magnetic_encoder_id].qspi_cfg,
                     &magnetic_encoder_runtime[magnetic_encoder_id].qspi_runtime);
    driver_dma_init(&magnetic_encoder_cfg[magnetic_encoder_id].rx_dma_cfg,
                    &magnetic_encoder_runtime[magnetic_encoder_id].rx_dma_runtime);

    driver_dma_setSourceDestinationAddress(&magnetic_encoder_runtime[magnetic_encoder_id].tx_dma_runtime,
                                           (uint32)&magnetic_encoder_runtime[magnetic_encoder_id].dma_command_buffer,
                                           ((uint32)&magnetic_encoder_runtime[magnetic_encoder_id].qspi_runtime.qspi_channelhn.spiMaster->qspi->DATAENTRY[magnetic_encoder_runtime[magnetic_encoder_id].qspi_runtime.qspi_channelhn.channelId % 8].U));
    driver_dma_setSourceDestinationAddress(&magnetic_encoder_runtime[magnetic_encoder_id].rx_dma_runtime,
                                           ((uint32)&magnetic_encoder_runtime[magnetic_encoder_id].qspi_runtime.qspi_channelhn.spiMaster->qspi->RXEXIT),
                                           (uint32)&magnetic_encoder_runtime[magnetic_encoder_id].dma_receive_buffer);

    driver_gtm_atom_timer_start(&magnetic_encoder_runtime[magnetic_encoder_id].gtm_atom_timer_runtime);
    driver_dma_start(&magnetic_encoder_runtime[magnetic_encoder_id].tx_dma_runtime);
    driver_dma_start(&magnetic_encoder_runtime[magnetic_encoder_id].rx_dma_runtime);
}

/**
 * @brief 初始化全部已配置的磁编码器设备。
 * @param[in] void 无参数。
 * @return void
 */
void device_magnetic_encoder_init_all(void)
{
    device_magnetic_encoder_init(DEVICE_MAGNETIC_ENCODER_1);
    device_magnetic_encoder_init(DEVICE_MAGNETIC_ENCODER_2);
}

/**
 * @brief 注册指定磁编码器传输完成后的回调函数。
 * @param[in] magnetic_encoder_id 磁编码器设备编号。
 * @param[in] device_magnetic_encoder_callback 回调函数指针。
 * @return void
 */
void device_magnetic_encoder_register_callback(device_magnetic_encoder_id_t magnetic_encoder_id,
                                               void (*device_magnetic_encoder_callback) (void))
{
    device_magnetic_encoder_runtime_t* magnetic_encoder_runtime = device_magnetic_encoder_runtime_table_get();
    magnetic_encoder_runtime[magnetic_encoder_id].device_magnetic_encoder_callback = device_magnetic_encoder_callback;
}

/**
 * @brief 读取磁编码器原始角度值。
 * @param[in] magnetic_encoder_id 磁编码器设备编号。
 * @return 原始角度值。
 */
uint16 device_magnetic_encoder_read_raw_angle(device_magnetic_encoder_id_t magnetic_encoder_id)
{
    device_magnetic_encoder_angle_reg_t angle_reg;

    angle_reg.U = device_magnetic_encoder_read_register(magnetic_encoder_id,
                                                        DEVICE_MAGNETIC_ENCODER_REGISTER_ANGLE);

    return angle_reg.B.angle;
}

/**
 * @brief 读取并换算磁编码器角度值。
 * @param[in] magnetic_encoder_id 磁编码器设备编号。
 * @return 角度值，单位：度。
 */
float32 device_magnetic_encoder_read_angle_degree(device_magnetic_encoder_id_t magnetic_encoder_id)
{
    return ((float32)device_magnetic_encoder_read_raw_angle(magnetic_encoder_id)
            * DEVICE_MAGNETIC_ENCODER_ANGLE_DEGREE_PER_LSB);
}

/**
 * @brief 读取磁编码器磁场强度值。
 * @param[in] magnetic_encoder_id 磁编码器设备编号。
 * @return 磁场强度寄存器值。
 */
uint16 device_magnetic_encoder_read_magnitude(device_magnetic_encoder_id_t magnetic_encoder_id)
{
    device_magnetic_encoder_magnitude_reg_t magnitude_reg;

    magnitude_reg.U = device_magnetic_encoder_read_register(magnetic_encoder_id,
                                                            DEVICE_MAGNETIC_ENCODER_REGISTER_MAGNITUDE);

    return magnitude_reg.B.magnitude;
}

/**
 * @brief 读取磁编码器自动增益控制值。
 * @param[in] magnetic_encoder_id 磁编码器设备编号。
 * @return AGC 寄存器值。
 */
uint16 device_magnetic_encoder_read_agc(device_magnetic_encoder_id_t magnetic_encoder_id)
{
    device_magnetic_encoder_agc_reg_t agc_reg;

    agc_reg.U = device_magnetic_encoder_read_register(magnetic_encoder_id,
                                                      DEVICE_MAGNETIC_ENCODER_REGISTER_AGC);

    return agc_reg.B.agc;
}

/**
 * @brief 读取磁编码器错误寄存器值。
 * @param[in] magnetic_encoder_id 磁编码器设备编号。
 * @return 错误寄存器值。
 */
uint16 device_magnetic_encoder_read_error(device_magnetic_encoder_id_t magnetic_encoder_id)
{
    device_magnetic_encoder_error_flag_reg_t error_reg;

    error_reg.U = device_magnetic_encoder_read_register(magnetic_encoder_id,
                                          DEVICE_MAGNETIC_ENCODER_REGISTER_ERROR);
    return error_reg.U;
}

IFX_INLINE uint16 device_magnetic_encoder_command_build(device_magnetic_encoder_register_t register_address, boolean is_read)
{
    uint16 command = ((uint16)register_address & DEVICE_MAGNETIC_ENCODER_REGISTER_ADDRESS_MASK);

    if (is_read != FALSE)
    {
        command |= DEVICE_MAGNETIC_ENCODER_REGISTER_READ_MASK;
    }

    return device_magnetic_encoder_parity_append(command);
}

IFX_INLINE uint16 device_magnetic_encoder_parity_append(uint16 value)
{
    uint16 parity_source = (uint16)(value & DEVICE_MAGNETIC_ENCODER_REGISTER_PARITY_DATA_MASK);
    uint16 parity = 0u;

    while (parity_source != 0u)
    {
        parity ^= (uint16)(parity_source & 0x1u);
        parity_source >>= 1u;
    }

    if (parity != 0u)
    {
        value |= DEVICE_MAGNETIC_ENCODER_REGISTER_PARITY_MASK;
    }

    return value;
}
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

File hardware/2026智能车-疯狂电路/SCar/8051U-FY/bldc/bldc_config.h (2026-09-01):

/*********************************************************************************************************************
 * COPYRIGHT NOTICE
 * Copyright (c) 2020,逐飞科技
 * All rights reserved.
 * 技术讨论QQ群：一群：179029047(已满)  二群：244861897(已满)  三群：824575535
 *
 * 以下所有内容版权均属逐飞科技所有，未经允许不得用于商业用途，
 * 欢迎各位使用并传播本程序，修改内容时必须保留逐飞科技的版权声明。
 *
 * @file        		pit_timer
 * @company	   		成都逐飞科技有限公司
 * @author     		逐飞科技(QQ790875685)
 * @version    		查看doc内version文件 版本说明
 * @Software 		MDK FOR C251 V5.60
 * @Target core		STC32G12K128
 * @Taobao   		https://seekfree.taobao.com/
 * @date        	2024-01-22
 ********************************************************************************************************************/

#ifndef _bldc_config_h_
#define _bldc_config_h_


// 40000000 / 43333 = 923.08
// 40000000 为系统频率40Mhz
// 43333为43.333Khz

#define BLDC_PWM_ARR_MAX                (923)           // PWM的最大占空比，需要自行根据PWM初始化去计算

#define BLDC_MAX_DUTY                   (15)            // 启动最大占空比，单位百分之一

#define BLDC_MIN_DUTY                   (5)             // 启动最小占空比，单位百分之一

#define BLDC_PWM_DEADTIME               (5)             // PWM输出死区

#define BLDC_MIN_BATTERY                (11000)         // 最小电压，单位mv，当检测到电压低于此值电机停转
    
#define BLDC_COMMUTATION_FAILED_MAX     (300)           // 换相错误最大次数 大于这个次数后认为电机堵转
    
#define BLDC_START_DELAY                (10000)         // 当遇到堵转后电机停止时间，之后电机会再次尝试启动（单位0.05ms）

#define BLDC_CLOSE_LOOP_WAIT            (200 )          // 闭环等待换向次数

#define BLDC_OPEN_LOOP_WAIT             (200 )          // 闭环等待换向次数

#define BLDC_SPEED_INCREMENTAL          (20 )            // 加减速响应 1-20，可修改这个提高加速响应，
                                                        // 设置20响应速度最慢，设置1响应速度最快。
                                                        // 响应速度越快，越容易出现换相错误，所以建议从20开始，一点一点减小。

#define BLDC_POLES                      (6)             // 电机极对数

#define BLDC_BEEP_ENABLE                (1 )            // 1:使能上电电机鸣叫功能 0：禁用
    
#define BLDC_BEEP_VOLUME                (60)            // 电机鸣叫声音大小 0-100

#define BLDC_MOTOR_ANGLE                (3)             // 马达进角，进入比较器中断后，延时多少度进行换相
                                                        // 范围0-30度

#define BLDC_USE_SINE_START             (1)             // 使用正弦启动

#define BLDC_USR_COMPLEMENTARY          (1)             // 1:使能互补输出 0：禁用

#define BLDC_USR_DUTY                   (0)             // 目标占空比来源：0=外部 PWM 捕获；1~100=宏固定百分比
                                                        // 0        = 由输入捕获换算油门，无有效 PWM 时占空比清零
                                                        // 1~100    = 忽略外部 PWM，目标占空比恒为本宏数值（1%~100%），便于调试

#endif

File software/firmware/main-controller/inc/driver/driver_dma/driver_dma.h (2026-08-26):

#ifndef MAD_CIRCUITS_DRIVER_DMA_H
#define MAD_CIRCUITS_DRIVER_DMA_H

#include "IfxDma_Dma.h"

#define DMA_CHANNEL_MAGNETIC_ENCODER1_GTM_ATOM_TIMER_TO_QSPI IfxDma_ChannelId_5
#define DMA_CHANNEL_MAGNETIC_ENCODER2_GTM_ATOM_TIMER_TO_QSPI IfxDma_ChannelId_6
#define DMA_CHANNEL_MAGNETIC_ENCODER1_QSPI_TO_INTERRUPT IfxDma_ChannelId_7
#define DMA_CHANNEL_MAGNETIC_ENCODER2_QSPI_TO_INTERRUPT IfxDma_ChannelId_8

#define DMA_CHANNEL_PHOTOTUBE_GROUP0_EVADC_TO_INTERRUPT IfxDma_ChannelId_9
#define DMA_CHANNEL_PHOTOTUBE_GROUP1_EVADC_TO_INTERRUPT IfxDma_ChannelId_17
#define DMA_CHANNEL_PHOTOTUBE_GROUP2_EVADC_TO_INTERRUPT IfxDma_ChannelId_23

#define DMA_CHANNEL_TASK1_INTERRUPT IfxDma_ChannelId_25
#define DMA_CHANNEL_TASK2_INTERRUPT IfxDma_ChannelId_26
#define DMA_CHANNEL_TASK3_INTERRUPT IfxDma_ChannelId_27
#define DMA_CHANNEL_TASK4_INTERRUPT IfxDma_ChannelId_28
#define DMA_CHANNEL_TASK5_INTERRUPT IfxDma_ChannelId_29
#define DMA_CHANNEL_TASK6_INTERRUPT IfxDma_ChannelId_30
#define DMA_CHANNEL_TASK7_INTERRUPT IfxDma_ChannelId_31
#define DMA_CHANNEL_TASK8_INTERRUPT IfxDma_ChannelId_32

#define DMA_CHANNEL_CARRIER1 IfxDma_ChannelId_33
#define DMA_CHANNEL_CARRIER2 IfxDma_ChannelId_34
#define DMA_CHANNEL_CARRIER3 IfxDma_ChannelId_35
#define DMA_CHANNEL_CARRIER4 IfxDma_ChannelId_36
#define DMA_CHANNEL_CARRIER5 IfxDma_ChannelId_37
#define DMA_CHANNEL_CARRIER6 IfxDma_ChannelId_38
#define DMA_CHANNEL_CARRIER7 IfxDma_ChannelId_39
#define DMA_CHANNEL_CARRIER8 IfxDma_ChannelId_40



#define DMA_PRIORITY_MAGNETIC_ENCODER1_GTM_ATOM_TIMER_TO_QSPI IfxDma_ChannelBusPriority_medium
#define DMA_PRIORITY_MAGNETIC_ENCODER2_GTM_ATOM_TIMER_TO_QSPI IfxDma_ChannelBusPriority_medium
#define DMA_PRIORITY_MAGNETIC_ENCODER1_QSPI_TO_INTERRUPT IfxDma_ChannelBusPriority_medium
#define DMA_PRIORITY_MAGNETIC_ENCODER2_QSPI_TO_INTERRUPT IfxDma_ChannelBusPriority_medium

#define DMA_PRIORITY_PHOTOTUBE_GROUP0_EVADC_TO_INTERRUPT IfxDma_ChannelBusPriority_medium
#define DMA_PRIORITY_PHOTOTUBE_GROUP1_EVADC_TO_INTERRUPT IfxDma_ChannelBusPriority_medium
#define DMA_PRIORITY_PHOTOTUBE_GROUP2_EVADC_TO_INTERRUPT IfxDma_ChannelBusPriority_medium

#define DMA_PRIORITY_TASK1_INTERRUPT IfxDma_ChannelBusPriority_medium
#define DMA_PRIORITY_TASK2_INTERRUPT IfxDma_ChannelBusPriority_medium
#define DMA_PRIORITY_TASK3_INTERRUPT IfxDma_ChannelBusPriority_medium
#define DMA_PRIORITY_TASK4_INTERRUPT IfxDma_ChannelBusPriority_medium
#define DMA_PRIORITY_TASK5_INTERRUPT IfxDma_ChannelBusPriority_medium
#define DMA_PRIORITY_TASK6_INTERRUPT IfxDma_ChannelBusPriority_medium
#define DMA_PRIORITY_TASK7_INTERRUPT IfxDma_ChannelBusPriority_medium
#define DMA_PRIORITY_TASK8_INTERRUPT IfxDma_ChannelBusPriority_medium

#define DMA_PRIORITY_CARRIER1 IfxDma_ChannelBusPriority_low
#define DMA_PRIORITY_CARRIER2 IfxDma_ChannelBusPriority_low
#define DMA_PRIORITY_CARRIER3 IfxDma_ChannelBusPriority_low
#define DMA_PRIORITY_CARRIER4 IfxDma_ChannelBusPriority_low
#define DMA_PRIORITY_CARRIER5 IfxDma_ChannelBusPriority_low
#define DMA_PRIORITY_CARRIER6 IfxDma_ChannelBusPriority_low
#define DMA_PRIORITY_CARRIER7 IfxDma_ChannelBusPriority_low
#define DMA_PRIORITY_CARRIER8 IfxDma_ChannelBusPriority_low

typedef struct
{
    Ifx_DMA* dma_module;
    IfxDma_Dma_Config dma_modulecfg;
    IfxDma_Dma_ChannelConfig dma_channelcfg;
} driver_dma_cfg_t;

typedef struct
{
    IfxDma_Dma dma_modulehn;
    IfxDma_Dma_Channel dma_channelhn;
} driver_dma_runtime_t;

void driver_dma_init(driver_dma_cfg_t* dma_cfg, driver_dma_runtime_t* dma_runtime);
void driver_dma_setSourceDestinationAddress(driver_dma_runtime_t* dma_runtime, uint32 source_address, uint32 destination_address);
void driver_dma_start(driver_dma_runtime_t* dma_runtime);

#endif

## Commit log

2026-08-26 Separate drive and suction ESC firmware
2026-08-26 Exclude suction ESC build output
2026-08-26 Acknowledge MotorCycle upstream project
2026-08-27 Document M2 threaded CNC holes
2026-08-27 Add mechanical procurement checklist
    [MECHANICAL_PROCUREMENT_LIST.xlsx]
2026-08-27 Add procurement cost disclaimer
    [MECHANICAL_PROCUREMENT_LIST.xlsx]
2026-08-27 Complete procurement disclaimer
    [MECHANICAL_PROCUREMENT_LIST.xlsx]
2026-08-28 Add encoder magnet to procurement list
    [MECHANICAL_PROCUREMENT_LIST.xlsx]
2026-09-01 Add mechanical designs and smart car resources
    [侧板v3.2.0.SLDPRT, 侧板v3.2.6.STEP, 加强茎v3.0.0.SLDPRT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]
2026-09-29 Document threaded holes for motor side plate

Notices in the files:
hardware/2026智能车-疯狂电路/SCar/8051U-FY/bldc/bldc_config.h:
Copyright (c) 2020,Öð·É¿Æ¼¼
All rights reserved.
